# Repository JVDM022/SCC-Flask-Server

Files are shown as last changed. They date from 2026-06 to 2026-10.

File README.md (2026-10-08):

# scc-control-platform

A small SCADA-like research control platform for a thermal SCC/corrosion test rig. Arduino SCC firmware owns rig control behavior, while an Intel NUC USB gateway handles communications to the Flask backend. PostgreSQL stores the time series, and the backend derives alarms, pump-cycle statistics, ML temperature predictions, and advisory MPC heater PWM recommendations. The React HMI dashboard provides live monitoring, trends, alarms, events, ML predictions, MPC output, firmware updates, and equipment health views.

## Architecture

```text
Arduino SCC controller -> USB serial -> Intel NUC gateway -> Flask API -> PostgreSQL
                                                                  |-> alarms and events
                                                                  |-> pump-cycle extraction
                                                                  |-> ML prediction
                                                                  |-> advisory MPC
                                                                  |-> React HMI dashboard
```

## Docker Setup

```bash
docker compose up --build
```

Backend: `http://localhost:5050`  
Frontend: `http://localhost:5173`

## Frontend HMI

The HMI is a React + Vite + TypeScript app in `frontend/hmi-dashboard`. It uses React Query for API polling, Plotly for dark engineering charts, and modular dashboard pages for operations, analytics, ML models, MPC, digital twin simulation, equipment health, event intelligence, and settings.

```bash
cd frontend/hmi-dashboard
npm install
npm run dev
```

## Live Telemetry

The default live path reads Arduino CSV telemetry over USB on the Intel NUC and posts parsed JSON to Flask:

```bash
cd backend
python -m app.services.nuc_gateway --serial-port /dev/ttyACM0 --api-base-url http://localhost:5000
```

Set `API_WRITE_KEY` in both the backend and gateway environment when write authentication is enabled. Common NUC gateway variables:

```text
NUC_SERIAL_PORT=/dev/ttyACM0
NUC_SERIAL_BAUD=115200
SCC_API_BASE_URL=http://localhost:5000
NUC_DEVICE_ID=intel-nuc-gateway
NUC_AVRDUDE_COMMAND=avrdude
NUC_ARDUINO_UPLOAD_BAUD=115200
```

Legacy ESP32 relay telemetry is still supported through MQTT. Devices publish JSON to:

```text
scc/site/<site_id>/rig/<rig_id>/device/<device_id>/telemetry
```

The Flask backend subscribes to Mosquitto when `MQTT_ENABLED=1`, parses MQTT payloads, stores telemetry, and derives alarms, pump-cycle records, ML predictions, and MPC recommendations.

## API Endpoints

- `GET /api/latest`: latest telemetry row.
- `GET /api/history?minutes=60`: telemetry history for plotting.
- `GET /api/events?limit=100`: pump and hard-kill events.
- `GET /api/alarms/active`: active alarms.
- `GET /api/pump-cycles`: extracted pump cycle statistics.
- `GET /api/ml/prediction`: predicted temperatures for +1s, +5s, and +10s when models exist.
- `GET /api/mpc/recommendation`: advisory heater PWM recommendation.
- `POST /api/control/setpoint`: store a desired setpoint command.
- `POST /api/control/power`: queue a controller on/off command through the Intel NUC gateway.
- `POST /api/telemetry`: JSON telemetry ingest used by the Intel NUC gateway and development tools.
- `POST /api/telemetry/csv`: development/manual CSV import, not the live ESP32 path.

## Telemetry Format

Live MQTT telemetry is JSON. The development CSV import endpoint accepts CSV with or without a header. Headerless rows are parsed using this exact order:

```text
event,ms,temp_c,adc,dtemp_c_per_s,setpoint_c,mode,heater_pwm,heating,heater_lockout,pump_enabled,pump_allowed,pump_on,motor_pwm,motor_on_ms,motor_period_ms,temp_before_pump_c,min_temp_after_pump_c,last_pump_drop_c,recovery_time_s,manual_kill,hard_kill,uptime_s
```

Example:

```text
0,123456,126.42,222,-0.1300,125.00,3,184,1,0,1,1,0,155,150,30000,127.20,124.80,2.40,18.50,0,0,300
```

Event codes: `0` normal sample, `1` pump start, `2` pump end, `3` pump recovered, `4` hard kill, `5` sensor fault.

## Safety Philosophy

Arduino firmware and hardware own hard safety. Flask, ML, MPC, and the Intel NUC gateway are monitoring, communications, and advisory layers, not the only protection layer. Heater lockout, manual kill, and hard kill override all recommendations; MPC returns PWM 0 when any of those states is active.

## Manual Emergency Control

The Arduino starts in a fail-safe OFF state. The Operations HMI queues `SET_ON 1` to enable both heater control and the pump timer, and `SET_ON 0` to turn both outputs off. `KILL 1` immediately latches the system OFF; after `KILL 0`, the operator must deliberately select Turn On again. Set `API_WRITE_KEY` on the backend and `VITE_API_WRITE_KEY` on the frontend to the same value when command authentication is enabled. The NUC gateway polls:

```text
/api/firmware/commands/next?device=nuc
```

Pending manual kill and setpoint commands are delivered through that endpoint before Arduino OTA commands. Existing ESP32 relay firmware can still poll with `device=esp32` for legacy deployments.

## Dependency Explanation

- Flask: API server
- SQLAlchemy: ORM
- PostgreSQL: database
- pandas/numpy: data processing
- scikit-learn: ML models
- joblib: model persistence
- matplotlib/plotly: visualization
- APScheduler: background jobs
- pytest: testing
- xgboost/lightgbm: advanced ML models

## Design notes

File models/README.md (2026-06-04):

# Model Artifacts

Optional model files:

- `best_model_1s.joblib`
- `best_model_5s.joblib`
- `best_model_10s.joblib`
- `feature_columns.json`

Each model should predict delta temperature for its horizon. The backend reconstructs future temperature as `current_temp_c + predicted_delta_c`.

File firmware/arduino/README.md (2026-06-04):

# Arduino Firmware

Imported firmware project:

- `SCC-V1.4`: Arduino SCC controller firmware source and tests.

This firmware owns the thermal SCC rig control behavior. The ESP32 project under `firmware/esp32/ESP32-Relay` is only the relay/communications bridge.

The backend expects telemetry in the fixed CSV order documented in `docs/telemetry_format.md`.

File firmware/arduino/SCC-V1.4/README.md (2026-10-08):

# SCC-V1.4 Arduino Firmware

This firmware controls the Arduino Uno side of the SCC controller and emits CSV
telemetry over UART.

## Startup and Power Commands

The controller always boots with the heater and pump off. It will not begin
autotune, heating, or timed pump operation until it receives `SET_ON 1` over
UART. `SET_ON 0` turns both outputs off. `KILL 1` also turns both outputs off
and latches the emergency-stop state; after `KILL 0`, a new `SET_ON 1` command
is required to restart the rig.

## ESP32-Driven Firmware Update Prep

The optional `ENABLE_SOFTWARE_BOOTLOADER_ENTRY` feature adds a small UART command
entry point for an ESP32 to request a safe reset handoff before programming the
Arduino.

This does not flash the Arduino from the Arduino firmware. The ESP32 must act as
the programmer and provide the upload protocol.

When enabled, the Arduino accepts either command line:

```text
ENTER_BOOTLOADER
OTA_PREPARE
```

On a recognized command, the firmware:

- sets heater PWM to `0`
- turns the motor/pump off
- disables normal control outputs
- prints `OTA_READY`
- flushes serial output
- triggers an ATmega328P watchdog reset

The feature is disabled by default so normal builds keep UART output as CSV
telemetry only. Enable it explicitly at compile time, for example:

```ini
build_flags =
  -DENABLE_SOFTWARE_BOOTLOADER_ENTRY=1
```

For a reliable production update path, wire an ESP32 GPIO to the Arduino RESET
line and use that GPIO for bootloader entry/reset timing. Software reset into the
bootloader is bootloader-dependent and can be less reliable than a hardware
reset pulse.

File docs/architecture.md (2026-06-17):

# Architecture

The platform is a small SCADA-like research stack for a thermal SCC/corrosion test rig.

```text
Arduino SCC controller firmware
  -> USB serial
  -> Intel NUC gateway
  -> Flask telemetry and command APIs
  -> PostgreSQL storage
  -> alarm rules, pump-cycle extraction, ML prediction, MPC advisory logic
  -> React HMI dashboard
```

The Arduino firmware owns rig control behavior. The Intel NUC gateway is used only as a communications bridge to move telemetry, commands, and Arduino firmware update requests between the hardware-side controller and backend services. The ESP32 MQTT relay path remains available for legacy deployments.

The backend stores raw telemetry first, then derives alarms, events, pump-cycle records, ML predictions, and MPC recommendations. Live device telemetry enters through the JSON telemetry API when using the NUC gateway, or through MQTT when using the legacy ESP32 relay. The HMI reads backend endpoints through polling so it remains simple to run during early research.

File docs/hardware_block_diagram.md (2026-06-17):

# Hardware Block Diagram

This diagram reflects the current SCC control-platform firmware layout:

- Arduino Uno owns the thermal control loop, sensor readout, heater PWM, and pump/motor PWM.
- Intel NUC acts as the communications bridge between Arduino USB serial and the backend API.
- Arduino firmware updates are flashed from the NUC over USB with `avrdude`.

```mermaid
%%{init: {"theme": "base", "themeVariables": {"background": "#0b0f14", "mainBkg": "#121821", "secondBkg": "#0f151d", "primaryColor": "#121821", "primaryTextColor": "#e5e7eb", "primaryBorderColor": "#1f2937", "lineColor": "#64748b", "secondaryColor": "#0f151d", "tertiaryColor": "#101923", "fontFamily": "Inter, IBM Plex Sans, ui-sans-serif, system-ui, sans-serif", "edgeLabelBackground": "#0b0f14", "clusterBkg": "#0f151d", "clusterBorder": "#1f2937", "titleColor": "#e5e7eb", "nodeTextColor": "#e5e7eb"}}}%%
flowchart LR
  subgraph Rig["Thermal SCC / Corrosion Test Rig"]
    Bath["MgCl2 bath / specimen cell"]
    TempSensor["Temperature sensor / thermistor interface"]
    Heater["Heater element"]
    Pump["Pump / dosing motor"]
  end

  subgraph Power["Power Domains"]
    Logic5V["5 V logic supply"]
    NucPower["Intel NUC power"]
    LoadSupply["Load supply for heater and pump"]
  end

  subgraph Arduino["Arduino Uno SCC Controller"]
    A0["A0 THERM_PIN\nADC temperature input"]
    D6["D6 HEATER_PWM_PIN\nPWM heater command"]
    D9["D9 MOTOR_PIN\nPWM pump/motor command"]
    Serial0["UART Serial @ 115200\nCSV telemetry + commands"]
    Control["Autotune / PID / safety logic\n120-130 C safe window\nheater hard kill at 130 C"]
  end

  subgraph DriverStage["Power Driver Stage"]
    HeaterMosfet["Heater MOSFET / driver"]
    MotorDriver["Motor driver / MOSFET"]
  end

  subgraph NUC["Intel NUC USB Gateway"]
    UsbSerial["USB serial\n115200 baud"]
    Parser["CSV parser\nJSON telemetry poster"]
    CommandPoller["HTTP command poller\nKILL / SETPOINT / ARDUINO_OTA"]
    Avrdude["avrdude Arduino flasher"]
  end

  subgraph LocalStack["Local Computer / Backend Stack"]
    Flask["Flask backend\ntelemetry + command API"]
    Postgres["PostgreSQL"]
    HMI["React HMI dashboard"]
  end

  Bath --> TempSensor
  TempSensor -->|"analog temperature signal"| A0
  A0 --> Control
  Control --> D6
  Control --> D9
  D6 -->|"PWM, max 200/255"| HeaterMosfet
  D9 -->|"PWM: startup 180, run 155"| MotorDriver
  HeaterMosfet -->|"switched load power"| Heater
  MotorDriver -->|"switched load power"| Pump
  Heater --> Bath
  Pump --> Bath

  Serial0 <-->|"CSV telemetry upstream\ncommand lines downstream"| UsbSerial

  UsbSerial --> Parser
  UsbSerial --> Avrdude
  Parser -->|"POST /api/telemetry"| Flask
  CommandPoller <-->|"HTTP polling / command JSON"| Flask
  Avrdude <-->|"download artifact + ack status"| Flask
  Flask --> Postgres
  HMI <-->|"HTTP polling"| Flask

  Logic5V --> Arduino
  NucPower --> NUC
  LoadSupply --> HeaterMosfet
  LoadSupply --> MotorDriver

  classDef field fill:#0f151d,stroke:#22c55e,color:#e5e7eb,stroke-width:1px;
  classDef controller fill:#121821,stroke:#38bdf8,color:#e5e7eb,stroke-width:1px;
  classDef safety fill:#121821,stroke:#ef4444,color:#e5e7eb,stroke-width:1px;
  classDef comm fill:#101923,stroke:#38bdf8,color:#e5e7eb,stroke-width:1px;
  classDef backend fill:#121821,stroke:#64748b,color:#e5e7eb,stroke-width:1px;
  classDef driver fill:#0f151d,stroke:#f59e0b,color:#e5e7eb,stroke-width:1px;
  classDef power fill:#0f151d,stroke:#f59e0b,color:#e5e7eb,stroke-width:1px;

  class Bath,TempSensor,Heater,Pump field;
  class A0,D6,D9,Serial0 controller;
  class Control safety;
  class HeaterMosfet,MotorDriver driver;
  class UsbSerial,Parser,CommandPoller,Avrdude comm;
  class Flask,Postgres,HMI backend;
  class Logic5V,NucPower,LoadSupply power;

  style Rig fill:#0f151d,stroke:#1f2937,color:#e5e7eb
  style Power fill:#0b1118,stroke:#f59e0b,color:#e5e7eb
  style Arduino fill:#0f151d,stroke:#38bdf8,color:#e5e7eb
  style DriverStage fill:#0b1118,stroke:#f59e0b,color:#e5e7eb
  style NUC fill:#0f151d,stroke:#38bdf8,color:#e5e7eb
  style LocalStack fill:#0f151d,stroke:#64748b,color:#e5e7eb
```

## Pin And Signal Summary

| Endpoint | Signal | Notes |
| --- | --- | --- |
| Arduino A0 | Temperature ADC | Uses calibrated linear fit in firmware: `tempC = -0.1871 * adc + 167.97`. |
| Arduino D6 | Heater PWM | Drives heater MOSFET/driver. Firmware clamps heater PWM to `HEATER_PWM_MAX = 200`. |
| Arduino D9 | Pump/motor PWM | Drives pump/motor driver. Startup kick is `180`, normal PWM is `155`. |
| Arduino Serial | UART telemetry/commands | CSV telemetry is emitted at `115200` baud. Optional command handling supports bootloader prep when enabled. |
| Arduino USB | Serial telemetry/commands | Connects directly to the Intel NUC gateway. |
| Intel NUC gateway | USB + HTTP | Parses telemetry, posts to Flask, polls commands, and flashes Arduino `.hex` artifacts with `avrdude`. |

## Backend Interface

Telemetry is posted by the Intel NUC gateway to:

```text
POST /api/telemetry
```

The backend stores raw telemetry first, then derives alarms, pump cycles, ML predictions, and MPC advisory state for the HMI.

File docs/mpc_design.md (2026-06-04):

# MPC Design

The initial MPC module is advisory only. It evaluates a fixed set of candidate heater PWM values:

```python
[0, 64, 128, 184, 220, 255]
```

For each candidate, it estimates the 5-second future temperature using `models/best_model_5s.joblib` when present. If no model is available, the backend uses a simple fallback predictor so the endpoint remains usable during commissioning.

The cost function is:

```text
cost = (predicted_temp - setpoint_c)^2 + 0.0005*pwm^2 + 0.05*(pwm - previous_pwm)^2
```

If hard kill, manual kill, or heater lockout is active, the recommendation is forced to PWM 0.

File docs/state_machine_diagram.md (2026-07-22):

# State Machine Diagram

This diagram reflects the Arduino SCC controller firmware state flow in
`firmware/arduino/SCC-V1.4/src/controller.cpp` and
`firmware/arduino/SCC-V1.4/src/main.cpp`.

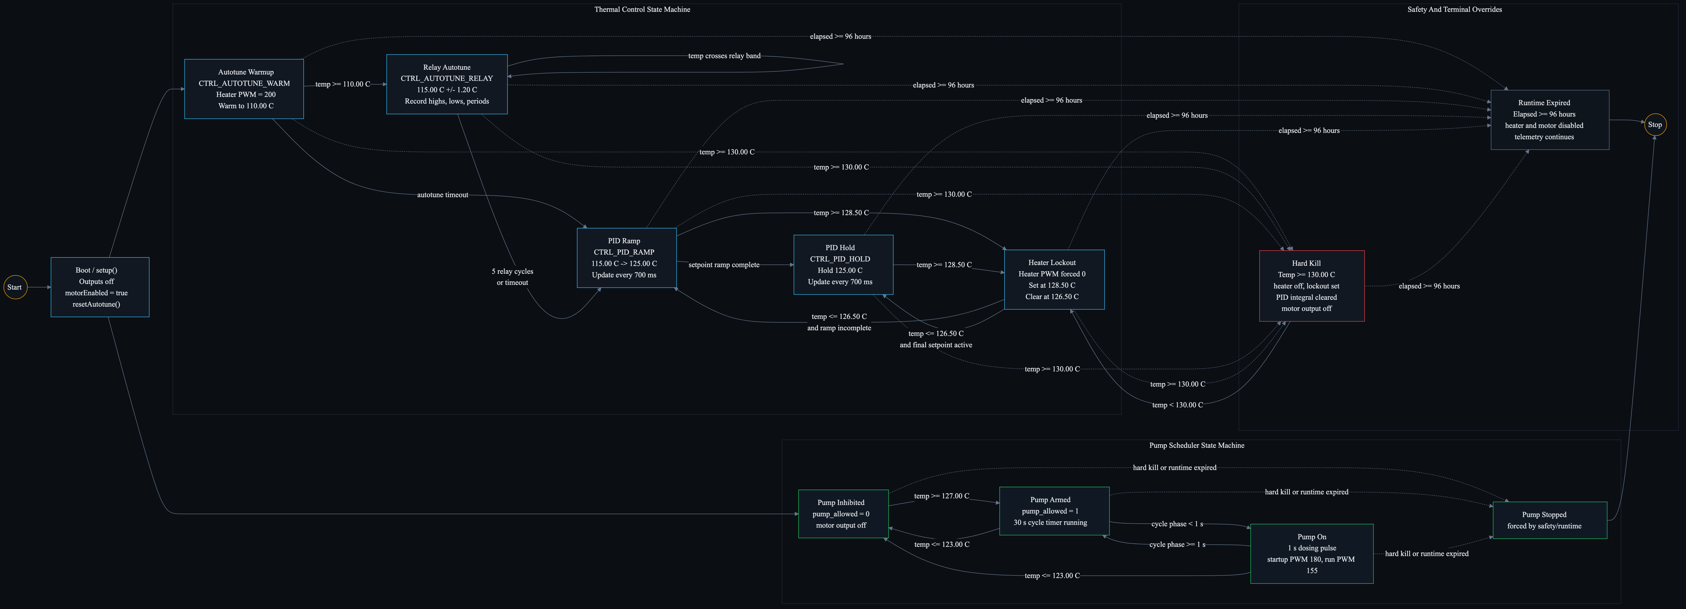
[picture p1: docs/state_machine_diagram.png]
SCC controller state machine


```mermaid
%%{init: {"theme": "base", "themeVariables": {"background": "#0b0f14", "mainBkg": "#121821", "secondBkg": "#0b0f14", "primaryColor": "#121821", "primaryTextColor": "#e5e7eb", "primaryBorderColor": "#1f2937", "lineColor": "#64748b", "secondaryColor": "#0b0f14", "tertiaryColor": "#0b0f14", "fontFamily": "Inter, IBM Plex Sans, ui-sans-serif, system-ui, sans-serif", "edgeLabelBackground": "#0b0f14", "clusterBkg": "#0b0f14", "clusterBorder": "#1f2937", "titleColor": "#e5e7eb", "nodeTextColor": "#e5e7eb"}}}%%
flowchart LR
  Start((Start)) --> Boot["Boot / setup()\nOutputs off\nmotorEnabled = true\nresetAutotune()"]

  subgraph Thermal["Thermal Control State Machine"]
    Warmup["Autotune Warmup\nCTRL_AUTOTUNE_WARMUP\nHeater PWM = 200\nWarm to 110.00 C"]
    Relay["Relay Autotune\nCTRL_AUTOTUNE_RELAY\n115.00 C +/- 1.20 C\nRecord highs, lows, periods"]
    Ramp["PID Ramp\nCTRL_PID_RAMP\n115.00 C -> 125.00 C\nUpdate every 700 ms"]
    Hold["PID Hold\nCTRL_PID_HOLD\nHold 125.00 C\nUpdate every 700 ms"]
    Lockout["Heater Lockout\nHeater PWM forced 0\nSet at 128.50 C\nClear at 126.50 C"]

    Warmup -->|"temp >= 110.00 C"| Relay
    Warmup -->|"autotune timeout"| Ramp
    Relay -->|"5 relay cycles\nor timeout"| Ramp
    Relay -->|"temp crosses relay band"| Relay
    Ramp -->|"setpoint ramp complete"| Hold
    Ramp -->|"temp >= 128.50 C"| Lockout
    Hold -->|"temp >= 128.50 C"| Lockout
    Lockout -->|"temp <= 126.50 C\nand ramp incomplete"| Ramp
    Lockout -->|"temp <= 126.50 C\nand final setpoint active"| Hold
  end

  Boot --> Warmup

  subgraph Pump["Pump Scheduler State Machine"]
    PumpInhibited["Pump Inhibited\npump_allowed = 0\nmotor output off"]
    PumpArmed["Pump Armed\npump_allowed = 1\n30 s cycle timer running"]
    PumpOn["Pump On\n1 s dosing pulse\nstartup PWM 180, run PWM 155"]
    PumpStopped["Pump Stopped\nforced by safety/runtime"]

    PumpInhibited -->|"temp >= 125.00 C"| PumpArmed
    PumpArmed -->|"cycle phase < 1 s"| PumpOn
    PumpOn -->|"cycle phase >= 1 s"| PumpArmed
    PumpArmed -->|"temp <= 123.00 C"| PumpInhibited
    PumpOn -->|"temp <= 123.00 C"| PumpInhibited
  end

  Boot --> PumpInhibited

  subgraph Overrides["Safety And Terminal Overrides"]
    HardKill["Hard Kill\nTemp >= 130.00 C\nheater off, lockout set\nPID integral cleared\nmotor output off"]
    RuntimeExpired["Runtime Expired\nElapsed >= 96 hours\nheater and motor disabled\ntelemetry continues"]
    Stop((Stop))
  end

  Warmup -.->|"temp >= 130.00 C"| HardKill
  Relay -.->|"temp >= 130.00 C"| HardKill
  Ramp -.->|"temp >= 130.00 C"| HardKill
  Hold -.->|"temp >= 130.00 C"| HardKill
  Lockout -.->|"temp >= 130.00 C"| HardKill
  HardKill -->|"temp < 130.00 C"| Lockout

  Warmup -.->|"elapsed >= 96 hours"| RuntimeExpired
  Relay -.->|"elapsed >= 96 hours"| RuntimeExpired
  Ramp -.->|"elapsed >= 96 hours"| RuntimeExpired
  Hold -.->|"elapsed >= 96 hours"| RuntimeExpired
  Lockout -.->|"elapsed >= 96 hours"| RuntimeExpired
  HardKill -.->|"elapsed >= 96 hours"| RuntimeExpired
  PumpInhibited -.->|"hard kill or runtime expired"| PumpStopped
  PumpArmed -.->|"hard kill or runtime expired"| PumpStopped
  PumpOn -.->|"hard kill or runtime expired"| PumpStopped
  RuntimeExpired --> Stop
  PumpStopped --> Stop

  classDef normal fill:#121821,stroke:#38bdf8,color:#e5e7eb,stroke-width:1px;
  classDef pump fill:#101923,stroke:#22c55e,color:#e5e7eb,stroke-width:1px;
  classDef safety fill:#121821,stroke:#ef4444,color:#e5e7eb,stroke-width:1px;
  classDef terminal fill:#0f151d,stroke:#64748b,color:#e5e7eb,stroke-width:1px;
  classDef start fill:#0f151d,stroke:#f59e0b,color:#e5e7eb,stroke-width:1px;

  class Boot,Warmup,Relay,Ramp,Hold,Lockout normal;
  class PumpInhibited,PumpArmed,PumpOn,PumpStopped pump;
  class HardKill safety;
  class RuntimeExpired terminal;
  class Start,Stop start;

  style Thermal fill:#0b0f14,stroke:#1f2937,color:#e5e7eb
  style Pump fill:#0b0f14,stroke:#1f2937,color:#e5e7eb
  style Overrides fill:#0b0f14,stroke:#1f2937,color:#e5e7eb
```

## State Notes

| State | Meaning |
| --- | --- |
| `AutotuneWarmup` | Initial control mode. Heater runs at fixed autotune PWM until the bath reaches `110.00 C`. |
| `AutotuneRelay` | Relay autotune oscillates around `115.00 C +/- 1.20 C` and records up to five cycles. |
| `PidRamp` | PID starts at the autotune target and ramps the active setpoint toward `125.00 C`. |
| `PidHold` | PID holds the final `125.00 C` setpoint. |
| `HeaterLockout` | Heater output is held off after `128.50 C` until temperature falls to `126.50 C`. |
| `HardKill` | At `130.00 C`, heater and motor outputs are forced off and lockout is set. |
| `RuntimeExpired` | After `96 hours`, heater and motor are disabled and the loop only emits telemetry. |
| `PumpScheduler` | Independent pump timer that enables dosing only with thermal headroom. |

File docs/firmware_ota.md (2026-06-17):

# Firmware Artifact Upload and OTA Commands

The HMI firmware page can upload firmware artifacts to the backend and queue OTA
commands. Arduino `.hex` updates are now handled by the Intel NUC USB gateway.
The legacy ESP32 relay command path remains available for older deployments.

## Artifact URLs

Artifacts are stored under `FIRMWARE_STORAGE_DIR`, which defaults to
`backend/storage/firmware`. They are served from:

```text
GET /firmware/artifacts/<filename>
```

Set `PUBLIC_BASE_URL` to the backend origin reachable by the NUC so queued OTA
commands contain artifact URLs the gateway can download.

## Command Lifecycle

The dashboard queues commands with:

```text
POST /api/firmware/commands
```

The Intel NUC gateway polls:

```text
GET /api/firmware/commands/next?device=nuc
```

The backend marks a command as `sent` when it is fetched. This avoids repeated
polling re-running the same OTA command. The NUC gateway acknowledges with:

```text
POST /api/firmware/commands/<cmd_id>/ack
```

Valid acknowledgement states are `started`, `success`, and `failed`.

## Intel NUC Arduino Flashing

Run the gateway on the NUC that is connected to the Arduino USB port:

```bash
cd backend
python -m app.services.nuc_gateway --serial-port /dev/ttyACM0 --api-base-url http://localhost:5000
```

Arduino flashing uses `avrdude` by default:

```text
avrdude -v -p atmega328p -c arduino -P <serial-port> -b 115200 -D -U flash:w:<artifact.hex>:i
```

Override the command and board parameters with `NUC_AVRDUDE_COMMAND`,
`NUC_ARDUINO_MCU`, `NUC_ARDUINO_PROGRAMMER`, and
`NUC_ARDUINO_UPLOAD_BAUD` if the NUC has a different Arduino toolchain.

## Safety Notes

- Do not expose firmware upload endpoints publicly without authentication.
- Firmware upload should require login and role permissions before production use.
- HTTPS is strongly recommended for OTA artifact URLs.
- Arduino `.hex` upload queues an `ARDUINO_OTA` command. The NUC gateway
  downloads that artifact, closes the serial monitor, runs `avrdude`, reopens
  serial, records OTA status, and acknowledges success or failure.
- ESP32 `.bin` upload remains available for legacy relay firmware only.

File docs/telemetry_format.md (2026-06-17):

# Telemetry Format

The Arduino emits CSV telemetry over USB. The Intel NUC gateway parses each row and posts JSON to the backend. CSV import tools may provide either a header plus row or a row without a header. If the header is missing, the backend parses values using this fixed column order:

```text
event,ms,temp_c,adc,dtemp_c_per_s,setpoint_c,mode,heater_pwm,heating,heater_lockout,pump_enabled,pump_allowed,pump_on,motor_pwm,motor_on_ms,motor_period_ms,temp_before_pump_c,min_temp_after_pump_c,last_pump_drop_c,recovery_time_s,manual_kill,hard_kill,uptime_s
```

Example row:

```text
0,123456,126.42,222,-0.1300,125.00,3,184,1,0,1,1,0,155,150,30000,127.20,124.80,2.40,18.50,0,0,300
```

Event codes:

- `0`: normal sample
- `1`: pump start
- `2`: pump end
- `3`: pump recovered
- `4`: hard kill
- `5`: sensor fault

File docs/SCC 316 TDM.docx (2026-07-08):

Stainless Steel 316 Stress Corrosion Cracking System

Technical Design, Operations, and Maintaince Manual

Document Number: SCC-TDM-001

Revision: 0.1 Draft

Author: John Jin

Date: June 9, 2026

Revision History:

Revision | Date | Author | Description
0.1 | June 9, 2026 | John Jin | Initial Draft

# 1. Introduction

## 1.1. Purpose

The Stress Corrosion Cracking (SCC) test system is an automated control system designed to heat the specimen and pump corrosive medium, such as magnesium chloride (MgCl2), while the sample undergoes creep loading. The platform integrates embedded hardware, process control algorithms, wireless communication, database infrastructure, and data analysis into a unified architecture [1–10].

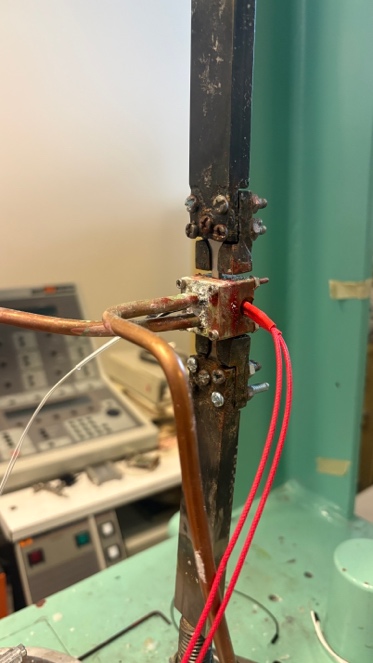
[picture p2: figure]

Fig 1. Testing setup

## 1.2. Scope

This document will include the following facets of the system:

- System architecture
- Hardware design
- Firmware design
- Backend infrastructure
- Database structure
- Control algorithms
- Safety systems
- Testing procedures
- Operational procedures

## 1.3. Objectives

The primary objectives of the SCC platform are:

1. Reliable process

The system must be designed to repeat the experiment process repeatedly. This process should be capable of being repeated with minimal human intervention to address any potential issues that may arise.

2. Reliable monitoring method

The system must be monitored with ease and reliability. All sensors must remain operational for an extended period beyond the duration of a single testing experiment.

3. Automated test control (temperature, pump frequency, etc.)

The PID system should be equipped with self-tuning capabilities and housed in a secure environment.

4. Safe heater operation

The temperature should not exceed 20 degrees Celsius above the set point or 350 degrees Celsius.

5. Continuous data logging

It’s important to log crucial parameters, including temperature, pump cycle, and time, in CSV format. These parameters encompass any data required for stress corrosion testing analysis, physics-informed machine learning models, or digital twins.

6. Remote monitoring capability

The parameters of the heater and pump should be adjustable remotely via the cloud. Firmware for both ESP32 and Arduino Uno R3 should support Over the Air (OTA) updates. Additionally, the Kill Command should also be executed via OTA.

# 2. System Requirements

This system is employed for conducting stress corrosion cracking experiments. It provides heating and a corrosive medium for the dog-bone samples during creep loading. The cartridge heater enables users to set the desired temperature, while the peristaltic pump propels MgCl2 (corrosive medium) through the copper pipes and cells, exposing the samples to the corrosive environment. The entire system should function in a quasi-automated mode.

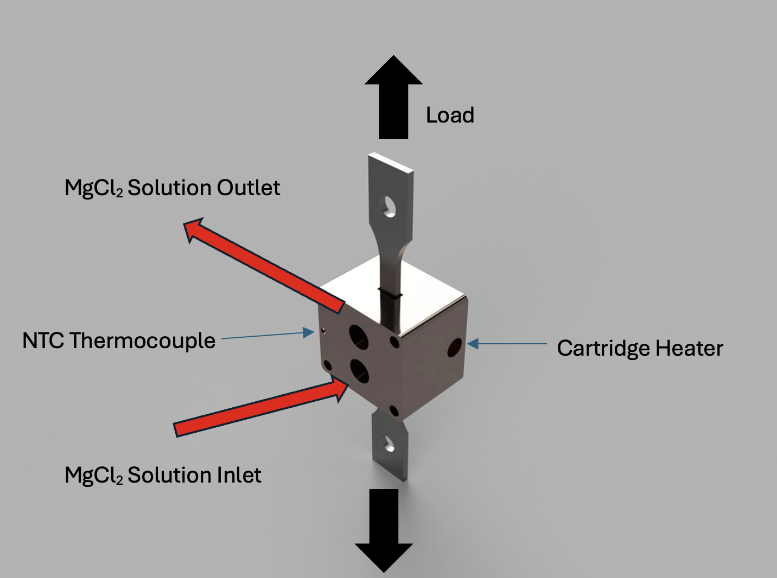
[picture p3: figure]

Fig 2. The hardware schematic of the system

## 2.1. Functional Requirements

ID | Requirement
FR-001 | Measure system temperature
FR-002 | Control heater output
FR-003 | Control pump circulations
FR-004 | Log data
FR-005 | Provide a method to monitor remotely
FR-006 | Execute safety shutdowns

Table 1. List of required functions for the system to perform

## 2.2. Performance Requirements

ID | Requirement | Target
PR-001 | Telemetry update rate | 1Hz
PR-002 | Data retention | ≥ 1 year
PR-003 | Uptime | >99%
PR-004 | Network Latency | <2 s

Table 2. List of performance targets the system needs to achieve

# 3. System Overview

## 3.1. Architecture

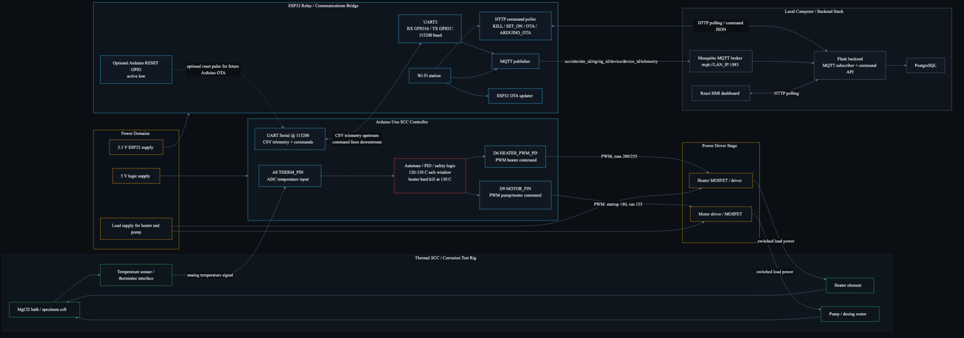
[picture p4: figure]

Fig 3. End-to-end system architecture

Fig 3 illustrates the end-to-end architecture of the SCC testing platform. The NTC thermistor and cartridge heater interface with the Arduino controller, which performs local control and data acquisition functions using the hardware components summarized in Table 3. The Arduino communicates with an ESP32 module that serves as a telemetry and command relay between the field hardware and backend infrastructure.

Sensor measurements, process data, and control messages are transmitted through the MQTT broker to the Flask API, which acts as the central integration layer for data management, command processing, analytics, and operator interaction. The software components that support these functions are summarized in Table 4. Processed data are stored in a PostgreSQL database, enabling long-term data retention, historical analysis, and performance monitoring.

The backend provides additional services, including alarm generation, pump-cycle extraction, machine-learning-based prediction, and advisory Model Predictive Control (MPC). Real-time communication between the backend and operator interface is implemented using a Socket.IO event bus [10]. This continuously updates the Human–Machine Interface (HMI) dashboard with process status, alarms, trends, and operator recommendations.

Operator-issued commands are routed through the Flask API and command store to the ESP32 command bridge, enabling remote actuation and over-the-air (OTA) firmware deployment. By separating field control, data acquisition, analytics, data storage, and user interaction into modular subsystems, the proposed architecture improves system scalability, maintainability, reliability, and future extensibility.

## 3.2. Hardware Components

The SCC testing platform consists of several hardware subsystems responsible for sensing, actuation, control, and communication. The primary hardware components and their functions are summarized in Table 3.

Component | Function
Arduino | Embedded controller
ESP32 | Telemetry and command relay
Thermistor | Temperature measurement
Cartridge heater | Thermal control
Pump | Fluid Circulation
SCC Shield | Power switching

Table 3. List of hardware in the system

  3.3. Software Components

The software architecture is organized into modular services responsible for control, communication, data management, and user interaction using MQTT, Flask, PostgreSQL, Socket.IO, and Docker technologies [1,4–10]. The major software components used in the SCC platform are summarized in Table 4.

Components | Function
Arduino Firmware | Local Control
ESP32 Firmware | Relay telemetry and commands
MQTT Broker | Messaging
Flask API | Backend services
Flask Server | Data Login and HMI interface
PostgreSQL | Data Storage
Dashboard | User interface HMI

Table 4. List of software tools used in the system

# 4. Hardware Design

## 4.1. Hardware Block Diagram

Fig 4 shows the hardware block diagram of the SCC testing platform. The system is centered around an Arduino UNO R3 microcontroller, which executes the local temperature control and pump management logic. The Arduino interfaces with a custom SCC Shield that provides sensor acquisition, power switching, and hardware interfacing functions. An NTC thermistor is connected to the SCC Shield for temperature measurement, while a cartridge heater and peristaltic pump are controlled through the shield to regulate the thermal and fluid circulation conditions of the SCC test environment. An ESP32 module serves as a communication bridge between the embedded controller and the supervisory control system. Through a Wi-Fi connection, the ESP32 exchanges telemetry and control commands with a remote Flask server, enabling real-time monitoring, data logging, and remote operation of the testing platform. This architecture separates local control functions from supervisory communication tasks, improving system modularity, maintainability, and scalability.

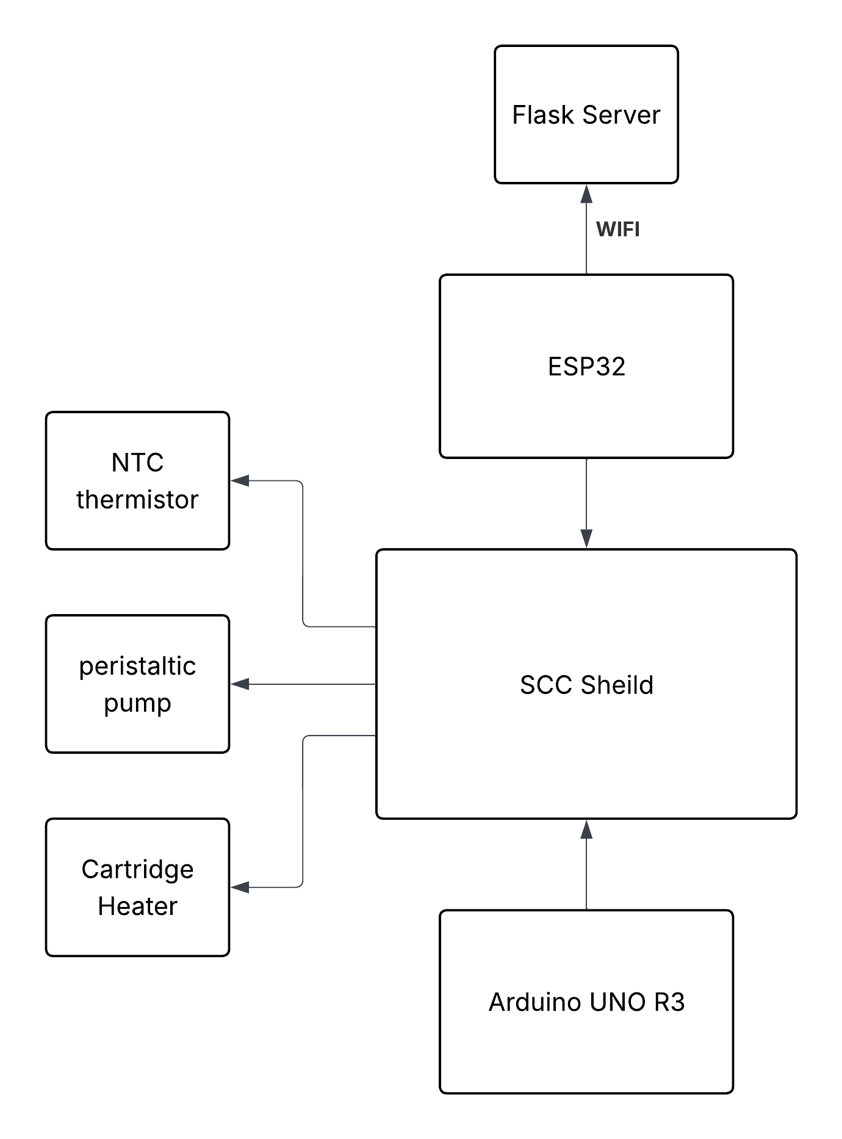
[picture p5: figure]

Fig 4. Hardware Block Diagram of the SCC Testing Platform

- Arduino Uno R3

Purpose: The Arduino Uno R3 serves as the primary embedded controller for the SCC testing platform and is based on the ATmega328P microcontroller architecture [3,15]. It acquires temperature measurements from the NTC thermistor, executes local control logic, manages heater and pump operation, and communicates process data to the ESP32 communication module.

Key Spec:

  - Microcontroller: ATmega328P
  - Operating Voltage: 5 V
  - Clock Speed: 16 MHz
  - Digital I/O Pins: 14
  - Analog Input Channels: 6
  - Communication Interfaces: UART, I²C, SPI

Firmware version: SCC V1.4

- ESP32

Purpose: The ESP32 functions as the communication bridge between the embedded control hardware and the supervisory control system using integrated Wi-Fi communication capabilities [2]. It receives telemetry data from the Arduino, publishes process information through MQTT, receives remote commands, and supports over-the-air (OTA) firmware updates.

Key Spec:

  - Processor: Dual-core Xtensa LX6
  - Clock Speed: Up to 240 MHz
  - Wireless Connectivity: 2.4 GHz Wi-Fi and Bluetooth
  - Flash Memory: 4 MB
  - Communication Interfaces: UART, SPI, I²C

Firmware version: ESP32-Relay

- Intel NUC

Purpose: The Intel NUC serves as the local supervisory computer hosting the Flask backend, MQTT broker, PostgreSQL database, and analytics services [14], MQTT broker, PostgreSQL database, data historian, alarm processing services, machine learning models, and Human–Machine Interface (HMI).

Key Spec:

  - Processor: Intel Core Series Processor
  - Operating System: Ubuntu Linux 24.04 LTS
  - Memory: 8 GB DDR4 RAM
  - Storage: 125 GB SSD
  - Network Connectivity: Gigabit Ethernet and Wi-Fi

Firmware version: SCC Control V0.1.1.4

  4.2. Sensor System
- Temperature Sensor:

Type: Negative Temperature Coefficient (NTC) Thermistor

Purpose:
The NTC thermistor provides continuous temperature measurement of the SCC test environment. The Arduino controller uses the sensor to regulate heater operation, monitor process conditions, and provide temperature feedback for data logging and future advanced control applications.

Sampling Method:
Analog voltage measurement through the Arduino Uno R3 analog-to-digital converter (ADC).

## 4.3. Shield Circuit

Overview of system shield design:

The SCC Shield is a custom-designed interface and power-control board that serves as the hardware integration layer between the Arduino Uno R3 and the SCC test rig components. The shield provides sensor signal conditioning, power distribution, and actuator control functions required for automated operation of the corrosion testing platform. Temperature measurements from the NTC thermistor are routed through an analog conditioning circuit and supplied to the Arduino’s analog-to-digital converter (ADC) for real-time temperature monitoring. High-current switching circuitry on the shield enables the Arduino to safely control the cartridge heater and peristaltic pump using low-voltage digital control signals. The shield also provides electrical isolation between low-power control electronics and higher-power load circuits, improving system reliability and protecting the microcontroller from electrical transients generated by inductive loads.

In addition to power-switching functionality, the SCC Shield consolidates wiring connections into a single interface board, simplifying system assembly, maintenance, and troubleshooting. The modular design allows sensors, actuators, and communication hardware to be connected through standardized connectors while maintaining compatibility with the Arduino platform. This architecture reduces wiring complexity and provides a scalable foundation for future expansion of sensing, control, and data acquisition capabilities.

Schematic:

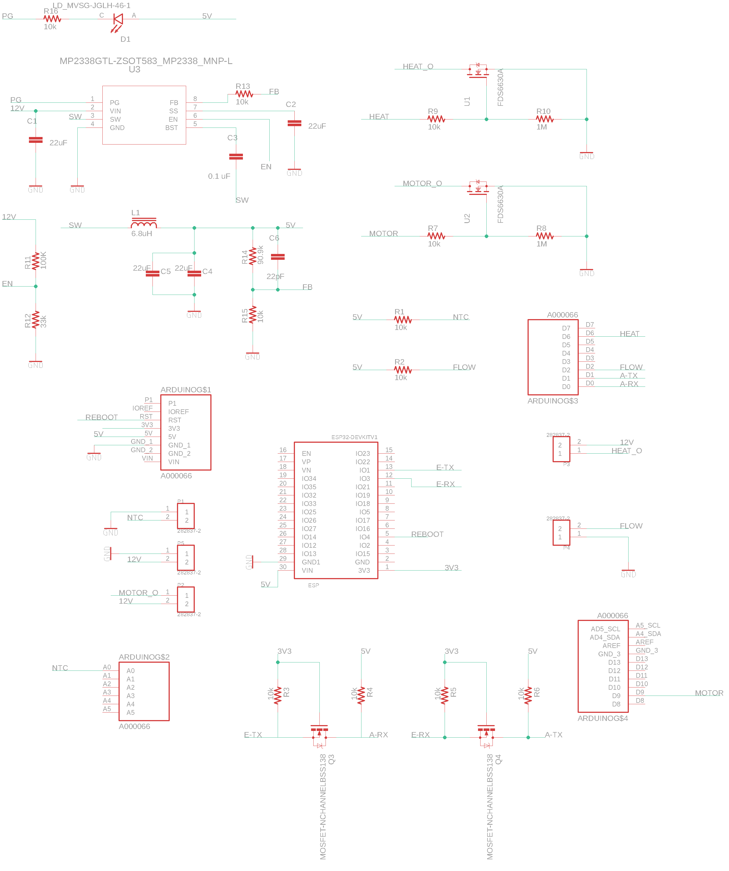
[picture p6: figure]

Fig 5. SCC Shield Electrical Schematic

Board Layout:

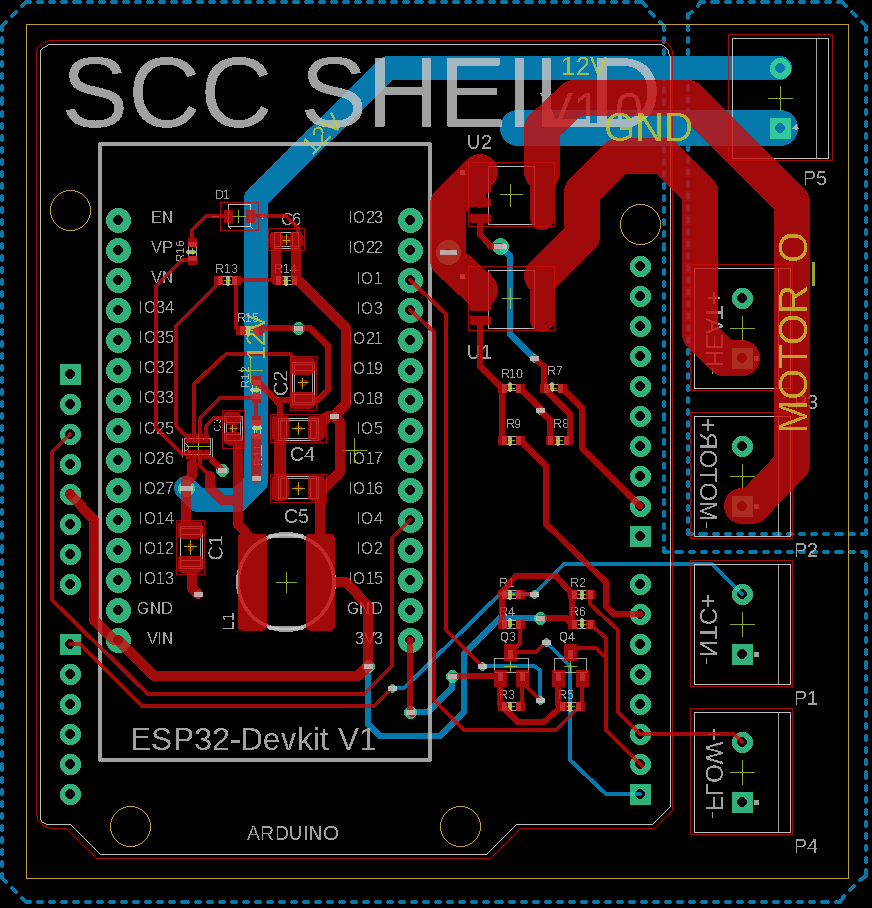
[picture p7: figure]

Fig 6. SCC shield board layout

- Heater Control Circuit

Description:

The heater control circuit provides low-side switching of the cartridge heater using an N-channel MOSFET (U1, FDS6630A). A digital output from the Arduino drives the MOSFET gate through a 10 kΩ gate resistor (R9), allowing the microcontroller to enable or disable heater power. A 1 MΩ pull-down resistor (R10) ensures that the MOSFET remains off during startup, reset conditions, or when the control signal is disconnected. The heater is supplied from the 12 V power rail and is switched under software control to maintain the desired SCC test temperature. This configuration provides efficient switching with minimal power dissipation while electrically isolating the microcontroller from the heater load current.

Operating Voltage: 12 VDC

Maximum Current: Determined by MOSFET rating and power connector limitations

Switching Method: Digital low-side MOSFET switching

Protection Features:

  - Gate pull-down resistor to prevent unintended activation
  - Logic-level MOSFET operation
  - Separation of control and power paths
  - Pump Control Circuit
- Pump Control Circuit

Description:

The pump control circuit uses a second N-channel MOSFET (U2, FDS6630A) to control power delivery to the peristaltic circulation pump. The Arduino drives the MOSFET gate through resistor R7, while pull-down resistor R8 maintains the MOSFET in an off state when no control signal is present. The pump receives power from the 12 V supply and is activated periodically according to the SCC control algorithm to circulate solution through the test apparatus. The MOSFET-based design enables reliable switching while minimizing mechanical wear associated with relay-based control methods.

CAUTION: Use a minimum 14 AWG wire for all motor power connections. The peristaltic pump can draw significant startup and operating current, and undersized wiring may result in excessive voltage drop, overheating, reduced motor performance, or potential damage to wiring and connectors.

Operating Voltage: 12 VDC

Current Draw: Dependent on pump operating conditions

Switching Method: Digital low-side MOSFET switching

Protection Features:

  - Gate pull-down resistor to prevent unintended activation
  - Logic-level MOSFET operation
  - Dedicated power routing for actuator loads

# 5. Software Design

## 5.1. Firmware Architecture

Fig 7 presents the operating state machine implemented within the SCC testing platform firmware. The control logic is organized into six primary operating states: Startup, Idle, Heating, Pumping, Lockout, and Emergency Shutdown. Measured temperature, user-defined setpoints, pump scheduling requirements, and safety conditions determine state transitions. During normal operation, the controller transitions from Startup to Idle, where system readiness is verified. When the measured temperature falls below the configured setpoint, the controller enters the Heating state and activates the cartridge heater. Once the target temperature is reached, the system returns to Idle and periodically executes Pumping cycles to circulate the test solution. Safety monitoring is continuously active throughout all operating states. If an abnormal temperature drop is detected following a pump cycle, the controller enters Lockout mode to prevent ineffective heating and excessive actuator cycling. Critical faults, including excessive temperature, sensor failure, or manual emergency stop commands, force the system into Emergency Shutdown mode, where all outputs are disabled until operator intervention occurs. This state-based architecture improves system reliability, predictability, and operational safety by clearly separating normal control functions from fault-handling behavior.

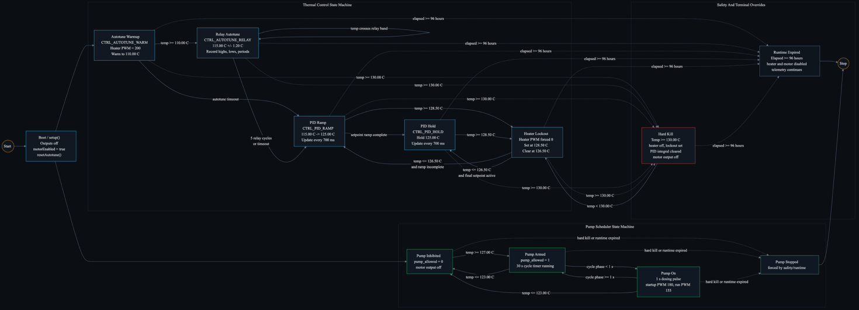
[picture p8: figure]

Fig7. SCC Control State Machine Annotation

## 5.2. Operating States

  1. Startup

The Startup state is entered immediately after power-up or system reset. During this phase, the controller initializes hardware peripherals, verifies sensor communication, loads configuration parameters, and establishes communication with the ESP32 telemetry module. All outputs remain disabled until initialization is successfully completed. Upon successful startup, the controller transitions to the Idle state.

  2. Idle

The Idle state represents the normal standby operating condition. In this state, the controller continuously monitors process temperature, evaluates pump scheduling timers, and checks safety conditions while maintaining all actuators in a safe state. If the measured temperature falls below the desired setpoint, the system transitions to the Heating state. If a scheduled circulation cycle is required and operating conditions permit, the controller transitions to the Pumping state.

  3. Heating

The Heating state regulates the cartridge heater to raise the process temperature toward the user-defined setpoint. Temperature measurements from the NTC thermistor are continuously monitored to prevent overheating and ensure stable thermal control. When the target temperature is achieved, the heater is disabled and the controller returns to the Idle state. Safety monitoring remains active throughout the heating process.

  4. Pumping

The Pumping state activates the circulation pump for a predefined duration to ensure fluid mixing and representative temperature measurements. During pump operation, the controller records thermal response characteristics, including temperature drop and recovery behavior. Upon completion of the pump cycle, the system returns to the Idle state. If abnormal cooling or unsafe operating conditions are detected, the controller may transition to the Lockout or Emergency Shutdown state.

  5. Lockout

The Lockout state is a protective operating mode used to prevent repeated heating and pumping cycles under unfavorable conditions. Lockout may be triggered when the temperature fails to recover adequately after a pump cycle or when operating limits defined by the control strategy are exceeded. While in Lockout, heater and pump operations are restricted until acceptable process conditions are restored. Once recovery criteria are met, the controller automatically returns to the Idle state.

  6. Emergency Shutdown

The Emergency Shutdown state is the highest-priority safety state. It is entered whenever a critical fault condition is detected, such as excessive temperature, sensor failure, communication failure, hardware fault, or a manual emergency stop command. Upon entry, all actuators are immediately disabled and an emergency event is logged and transmitted to the backend system. Recovery from Emergency Shutdown requires operator acknowledgement and corrective action before normal operation can resume.

## 5.3. Event Codes

The SCC firmware records key operational events using a standardized event-code system to support data logging, diagnostics, and backend analytics. Each event is transmitted through the telemetry interface and stored within the database, allowing system behavior to be reconstructed during testing and fault investigation. The event codes used by the platform are summarized in table 5.

Code | Event
0 | Normal Sample
1 | Pump start
2 | Pump end
3 | Recovery complete
4 | Hard kill

Table 5. Event codes generated by the SCC firmware for operational logging and system monitoring.

## 5.4. MQTT Topics

MQTT serves as the primary messaging layer between the ESP32 gateway and the backend infrastructure and enables lightweight publish-subscribe communication for industrial telemetry applications [1,7]. Topic namespaces are structured using site, rig, and device identifiers to support multi-device deployments and simplify message routing. Telemetry topics provide real-time process data, while dedicated status, alarm, heartbeat, and OTA topics support operational monitoring, fault management, and firmware lifecycle control. The MQTT topic definitions used by the SCC platform are listed in Table 6.

Topic | Direction | Description
scc/site/<site_id>/rig/<rig_id>/device/<device_id>/telemetry | Publish | Live ESP32 telemetry
scc/site/<site_id>/rig/<rig_id>/device/<device_id>/ | Publish | Device state
scc/site/<site_id>/rig/<rig_id>/device/<device_id>/alarm | Publish | Device alarms
scc/site/<site_id>/rig/<rig_id>/device/<device_id>/heartbeat | Publish | Device heartbeat
scc/site/<site_id>/rig/<rig_id>/device/<device_id>/ota/status | Publish | OTA status

Table 6. MQTT topics used for device telemetry, status reporting, alarm notification, heartbeat monitoring, and OTA firmware management within the SCC platform.

# 6. Database Design

## 6.1. Database Overview

The SCC platform utilizes a PostgreSQL database as the central repository for process telemetry, alarms, events, and predictive analytics data [4]. MQTT message logs, system events, alarms, pump-cycle statistics, machine-learning (ML) prediction outputs, model predictive control (MPC) recommendations, and firmware update records. Telemetry data are generated by the Arduino controller, transmitted through the ESP32 communication gateway using MQTT, processed by the Flask backend, and stored within the database for visualization, analytics, alarm generation, and decision-support functions.

The database architecture provides persistent storage for both real-time and historical process information, enabling trend analysis, fault investigation, predictive modeling, and long-term system performance evaluation.

Database Engine: PostgreSQL

Backend ORM: SQLAlchemy [9]

Primary Data Source: ESP32 MQTT Telemetry

Primary Data Table: telemetry

Fig 8 illustrates the database architecture and data flow implemented within the SCC platform.

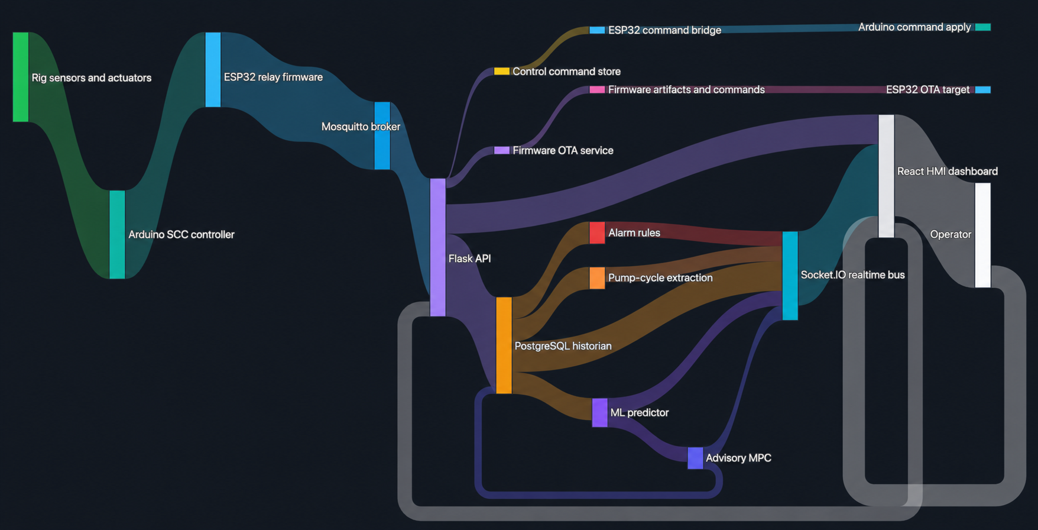
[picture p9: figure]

Fig 8. SCC database flow chart

## 6.2. Process Data Table

The telemetry table serves as the primary repository for process measurements and controller status information. Each telemetry record represents a complete snapshot of system operation at a specific point in time, including temperature measurements, controller states, pump metrics, safety indicators, and operational events. This structure enables historical reconstruction of system behavior, alarm analysis, machine-learning model training, and development of advisory control strategies.

The telemetry table schema is summarized in Table 7.

Table 7. Telemetry table schema used for storage of process measurements, controller states, safety indicators, and pump-cycle metrics within the SCC platform.

Field | Type | Key | Description
id | SERIAL | Primary Key | Unique telemetry record identifier
created_at | TIMESTAMPTZ | Indexed | Timestamp when the telemetry sample was stored
site_id | VARCHAR(80) | Indexed | Site identifier
rig_id | VARCHAR(120) | Indexed | Test rig identifier
device_id | VARCHAR(120) | Indexed | ESP32 device identifier
mqtt_topic | VARCHAR(255) | | MQTT topic associated with the received message
raw_payload | JSONB | | Original MQTT payload stored for traceability and debugging
event | INTEGER | | Event code generated by the controller
ms | INTEGER | | Controller runtime in milliseconds
temp_c | DOUBLE PRECISION | | Measured process temperature (°C)
adc | INTEGER | | Raw analog-to-digital converter value
dtemp_c_per_s | DOUBLE PRECISION | | Temperature rate of change (°C/s)
setpoint_c | DOUBLE PRECISION | | Temperature setpoint (°C)
mode | INTEGER | | Controller operating mode
heater_pwm | INTEGER | | Heater PWM duty cycle command
heating | INTEGER | | Heater active status flag
heater_lockout | INTEGER | | Heater lockout status flag
pump_enabled | INTEGER | | Pump enabled status flag
pump_allowed | INTEGER | | Pump permission status flag
pump_on | INTEGER | | Pump running status flag
motor_pwm | INTEGER | | Pump motor PWM duty cycle
motor_on_ms | INTEGER | | Pump activation duration (ms)
motor_period_ms | INTEGER | | Pump cycle period (ms)
temp_before_pump_c | DOUBLE PRECISION | | Temperature immediately before pump activation (°C)
min_temp_after_pump_c | DOUBLE PRECISION | | Minimum temperature observed after pump activation (°C)
last_pump_drop_c | DOUBLE PRECISION | | Temperature drop caused by the most recent pump cycle (°C)
recovery_time_s | DOUBLE PRECISION | | Temperature recovery time following a pump cycle (s)
manual_kill | INTEGER | | Manual emergency stop status flag
hard_kill | INTEGER | | Hard safety shutdown status flag
uptime_s | INTEGER | | Device uptime in seconds

Table 7. Telemetry table schema used for storage of process measurements, controller states, safety indicators, and pump-cycle metrics within the SCC platform.

The raw_payload field is stored as a PostgreSQL JSONB object to preserve the original MQTT message structure and provide traceability for debugging, validation, and future schema extensions.

## 6.3. Supporting Tables

In addition to the primary telemetry table, several supporting tables are used to manage events, alarms, firmware updates, machine-learning outputs, and control commands. These tables provide separation of concerns while maintaining relationships with the primary telemetry records.

Table 8. Supporting database tables and their functions.

Table | Purpose
events | Stores pump start, pump end, recovery, and hard-kill events
alarms | Stores active and cleared alarm records
pump_cycles | Stores pump-cycle recovery and temperature-drop statistics
devices | Tracks device identity, online status, heartbeat, and MQTT activity
mqtt_message_log | Stores received MQTT messages and validation status
ml_predictions | Stores machine-learning temperature predictions
mpc_recommendations | Stores advisory heater PWM recommendations
control_commands | Stores backend setpoint commands
firmware_devices | Tracks firmware status for connected devices
firmware_update_events | Logs firmware and OTA update events
firmware_artifacts | Stores uploaded firmware artifact metadata
firmware_commands | Stores firmware update commands and acknowledgements

Table 8. Supporting database tables and their functions.

## 6.4. Relationships

Relationships between tables are implemented using foreign-key references to maintain data integrity and support efficient querying of historical records. These relationships allow telemetry records to be linked with events, alarms, predictive models, firmware operations, and control actions.

The primary database relationships are summarized in Table 9.

Table 9. Database relationships used within the SCC platform.

Relationship | Description
events.telemetry_id -> telemetry.id | Links an event to the telemetry sample that produced it
alarms.telemetry_id -> telemetry.id | Links an alarm to the telemetry sample that triggered it
ml_predictions.telemetry_id -> telemetry.id | Links ML predictions to the source telemetry sample
firmware_update_events.device_id -> firmware_devices.device_id | Links firmware events to a firmware device
firmware_commands.artifact_id -> firmware_artifacts.id | Links firmware commands to uploaded firmware artifacts

Table 9. Database relationships used within the SCC platform.

## 6.5. Data Indexing Strategy

Database indexes are applied to frequently queried fields to improve query performance for dashboard visualization, historical analysis, alarm investigation, and device monitoring. Indexed columns are selected based on expected filtering and retrieval operations.

Column | Purpose
created_at | Time-series queries and trend analysis
site_id | Site-level filtering
rig_id | Rig-level filtering
device_id | Device history and device-specific searches
event | Event analysis and diagnostics
hard_kill | Safety event investigation

Table 10. Database indexing strategy.

## 6.6. Data Retention Policy

A structured data-retention policy is recommended to balance long-term analytical value with database storage requirements. Raw telemetry data are retained for operational monitoring, model training, and fault analysis, while summary records and critical system events are preserved for long-term historical reference.

The recommended retention policy is summarized in Table 11.

Data Type | Retention
Raw telemetry | 30 to 90 days
Events and alarms | 1 year
Pump-cycle summaries | Long-term retention
ML predictions and MPC recommendations | 90 days
MQTT message logs | 7 to 30 days
Firmware update events | Long-term retention

Table 11. Recommended database retention policy.

To ensure data integrity and disaster recovery capability, database backups should be performed on a regular schedule using PostgreSQL backup utilities. For production deployments, daily database backups and weekly archived snapshots are recommended. Additional off-site backup storage may be implemented for enhanced system resilience and long-term record preservation.

# 7. Control System Design

## 7.1. Control Objectives

The SCC platform is designed to regulate solution temperature during stress-corrosion-cracking (SCC) testing while maintaining safe and stable operation during heating, fluid circulation, and long-duration experiments. The control system combines closed-loop temperature regulation, pump-aware compensation, and firmware-level safety mechanisms to ensure reliable operation under varying thermal conditions.

The primary control objectives are summarized in Table 12.

Objective | Description
Maintain setpoint temperature | Control the heater output to reach and hold the target bath temperature.
Prevent overheating | Disable heating when the temperature approaches unsafe limits.
Minimize thermal oscillation | Use PID control and ramped setpoints to reduce overshoot and unstable cycling.
Compensate for pump disturbance | Add heater bias before and during pump operation to reduce temperature drop.
Ensure safe operation | Apply heater lockout, hard-kill logic, and runtime limits in firmware.

Table 12. Control objectives implemented within the SCC platform.

## 7.2. Current Control Architecture

The primary control loop is executed locally within the Arduino controller firmware. Temperature measurements are acquired through the NTC thermistor and used to generate heater PWM commands. The ESP32 functions as a communication gateway, forwarding telemetry and command messages between the controller and backend infrastructure. Higher-level functions, including data storage, alarm generation, machine-learning prediction, and advisory model predictive control (MPC), are executed within the backend system.

The current control architecture is summarized in Table 13.

Control Feature | Implementation
Main controller | Arduino firmware
Communication bridge | ESP32 relay
Control output | Heater PWM
Feedback input | Temperature sensor through ADC
Control interval | 700 ms
Final setpoint | 125.00 °C
Heater PWM maximum | 200
Hard-kill temperature | 130.00 °C
Heater lockout high threshold | 128.50 °C
Heater lockout reset threshold | 126.50 °C

Table 13. SCC control system configuration.

This architecture ensures that critical control and safety functions remain operational even if communication with the backend is interrupted.

## 7.3. Control Modes

The controller operates as a finite-state system consisting of multiple control modes that support autotuning, temperature regulation, and safety management. During startup, the controller performs relay-based autotuning to estimate PID parameters. Once tuning is completed, the controller transitions to PID-based operation and maintains the target process temperature.

The available control modes are summarized in Table 14.

Mode | Description
Autotune warmup | Heater warms the system until it reaches the autotune region.
Autotune relay | Relay cycling is used to estimate PID tuning parameters.
PID ramp | The active setpoint ramps gradually from the autotune target to the final setpoint.
PID hold | The controller holds the final setpoint using PID control.
Safety override | Heating is disabled during hard kill, manual kill, or heater lockout conditions.

Table 14. Controller operating modes.

The controller automatically transitions between modes based on measured temperature, tuning completion status, and safety conditions.

## 7.4. Safety Logic

Safety functions are implemented directly within the controller firmware to ensure protection independent of the database, dashboard, network connection, machine-learning models, or backend services. Firmware-level protection guarantees that unsafe operating conditions result in immediate corrective action regardless of external system status.

The implemented safety mechanisms are summarized in Table 15.

Safety Function | Trigger | Action
Heater lockout | Temperature >= 128.50 °C | Heater output disabled
Lockout reset | Temperature <= 126.50 °C | Heater may resume
Hard kill | Temperature >= 130.00 °C | Heater and pump are disabled
Manual kill | Operator or external safety input | Control recommendation forced to zero
Runtime limit | 96 hours | Heater and pump disabled

Table 15. Firmware safety functions.

The machine-learning and MPC systems operate exclusively in an advisory capacity and shall not be considered part of the primary safety layer.

## 7.5. Pump Aware Compensation.

Pump operation introduces a predictable thermal disturbance by circulating cooler fluid through the test system. To reduce temperature excursions caused by pumping events, the controller applies anticipatory heater bias both before and during pump operation.

The pump compensation parameters are summarized in Table 16.

Parameter | Value | Description
Pump period | 30000 ms | Pump cycle interval
Pump on time | 1000 ms | Pump active duration
Pre-bias window | 5000 ms | Heater bias starts before pump activation
Pre-bias PWM | +18 | Extra heater PWM before pump operation
Pump-on bias PWM | +28 | Extra heater PWM while pump is running

Table 16. Pump-aware compensation settings.

To reduce integral windup caused by predictable disturbances, the PID integrator is temporarily frozen while the pump is active.

## 7.6. Advisory Model Predictive Control (MPC)

An advisory Model Predictive Control (MPC) module is implemented within the backend architecture to evaluate future control actions and provide operator guidance. The MPC module does not directly control the heater; instead, it evaluates candidate heater PWM values and recommends an optimal action based on predicted thermal response.

Current MPC Status: Advisory Only

Future MPC Status: Closed-Loop Control Following Validation and Safety Review

The current MPC implementation is summarized in Table 17.

MPC Feature | Description
Candidate PWM values | 0, 64, 128, 184, 220, 255
Prediction horizon | 5 seconds
Model source | `best_model_5s.joblib` if available
Fallback behavior | Uses a simple predictor when no ML model exists
Safety override | Recommends PWM 0 during hard kill, manual kill, or heater lockout

Table 17. Advisory MPC configuration

The MPC cost function minimizes temperature error while penalizing excessive control effort and abrupt changes in heater output:

cost = (predicted_(temp) -setpoint_c )^2 +0.0005*pwm^2 +0.05*(pwm - previous_(pwm) )²

## 7.7. Machine Learning Roadmap

Model source: best_model_5s.joblib if available, generated using Scikit-learn and XGBoost model pipelines [11,12]. ML models provide temperature forecasting and anomaly detection capabilities that support process monitoring and future control-system enhancements. All ML outputs are advisory and do not override firmware-level safety protections.

Planned ML applications are summarized in Table 18.

Application | Purpose
Process Prediction | Forecast future process temperatures over short time horizons
Fault Detection | Identify abnormal heater, pump, or sensor behavior
Anomaly Detection | Detect unusual telemetry patterns during operation
Predictive Maintenance | Estimate equipment degradation using historical trends
MPC Support | Provide future temperature predictions for advisory MPC calculations

Table 18. Machine-learning applications within the SCC platform.

Current prediction horizons include short-term forecasts of +1 s, +5 s, and +10 s when trained models are available. Future development will focus on model validation, uncertainty quantification, adaptive control integration, and eventual deployment of closed-loop predictive control strategies.

# 8. Safety Analysis

The SCC control platform is designed so safety-critical decisions remain on the hardware side of the system. The Arduino controller and electrical interlocks own heater and pump shutdown behavior. The ESP32, Flask backend, database, HMI, ML model, and MPC service provide communication, monitoring, logging, alarms, and advisory recommendations only.

Backend alarms and dashboard notifications improve operator visibility, but they are not the primary protection layer. The rig must remain safe if the network, MQTT broker, database, server, HMI, ML model, or MPC endpoint fails.

## 8.1. Hazards

A hazard assessment was performed to identify potential failure modes, their consequences, and existing mitigation measures. The identified hazards are summarized in Table 19.

Hazard | Potential Consequence | Existing Mitigation
Bath overheating | Equipment damage, accelerated corrosion, unsafe test conditions, or operator burn hazard | Firmware heater lockout at 128.5 °C, hard kill at 130.0 °C, heater PWM limiting, and backend high-temperature alarms
Thermistor failure or invalid ADC reading | Incorrect temperature feedback resulting in uncontrolled heating | Sensor fault detection, ADC validation checks, heater shutdown, pump shutdown, lockout activation, and alarm generation
Pump failure or blocked flow | Poor solution circulation, invalid test results, and delayed thermal recovery | Pump telemetry monitoring, recovery-time analysis, and backend alarm generation
Pump operation without sufficient thermal headroom | Excessive temperature drop below operating conditions | Temperature-gated pump operation with configurable upper and lower thresholds
Heater output failure or excessive PWM command | Thermal runaway and equipment damage | Firmware lockout logic, hard-kill protection, PWM limiting, and recommended independent power isolation
Manual emergency shutdown | Delayed operator response during abnormal conditions | Manual kill command and provision for physical emergency-stop hardware
Network, MQTT, server, database, or HMI failure | Loss of monitoring, alarms, and remote control capability | Local firmware continues operation independently of backend services
ML or MPC recommendation error | Unsafe recommendation if treated as direct control action | MPC remains advisory only and cannot override firmware safety logic
Firmware update interruption | Uncertain controller state during firmware update operations | OTA preparation disables heater and motor outputs before reset
Excessive runtime or unattended operation | Continued operation beyond intended test duration | Firmware runtime limit and automatic shutdown functionality

Table 19. Hazard analysis and mitigation measures.

## 8.2. Safety Features

Multiple independent safety mechanisms are implemented within the SCC platform to prevent unsafe operation and reduce risk associated with hardware faults, software faults, and operator error.

The primary safety functions are summarized below:

- Heater Lockout: Heater output is disabled when measured temperature reaches 128.5 °C. Heating may resume only after temperature decreases below 126.5 °C.
- Hard Kill Protection: At 130.0 °C, the controller immediately disables heater and pump outputs, clears control commands, resets the PID integrator, activates lockout status, and generates a hard-kill event.
- Manual Kill Function: Operator-issued kill commands immediately disable heater and pump outputs and prevent further actuation until reset.
- Sensor Fault Detection: Invalid ADC values and thermistor fault conditions automatically disable all outputs and generate a fault event.
- Safe Startup Sequence: Heater and motor outputs remain disabled during initialization until controller state validation is complete.
- Pump Temperature Gating: Pump operation is permitted only within an approved temperature operating window.
- PWM Limiting: Heater PWM commands are constrained to a configurable maximum value to prevent excessive power output.
- PID Windup Protection: Integral accumulation is reset during lockout, hard-kill, manual-kill, and sensor-fault conditions.
- Safe OTA Preparation: Firmware update procedures disable all outputs before initiating reset or programming operations.
- Alarm Logging and Audit Trail: Critical safety events are recorded within the database and displayed through the HMI.
- Advisory-Only MPC: Model-based recommendations are prevented from overriding firmware safety states

## 8.3. Emergency Shutdown Procedure

In the event of abnormal operation or a hazardous condition, the following emergency shutdown procedure shall be performed:

1. Emergency shutdown order should issue a manual kill before disconnecting power only if HMI is available; otherwise, disconnect power first.
2. Disconnect the power
3. Verify that heater PWM output is zero and heater power is electrically isolated.
4. Verify that all pump and motor outputs are disabled.
5. Allow the bath temperature to decrease below the lockout reset threshold.
6. Record the event, including timestamp, measured temperature, active alarms, and operator actions.
7. Inspect the heater assembly, thermistor, pump system, power electronics, and enclosure for damage or abnormal conditions.
8. Restart operation only after the root cause has been identified and corrective actions have been completed.

## 8.4. Safety verification Tests

Safety functions shall be validated through functional testing before deployment. Verification tests are summarized in Table 20.

Safety Function | Test Method | Expected Result
Safe Startup | Power cycle controller while monitoring outputs | Outputs remain disabled during initialization
Heater Lockout | Raise temperature to 128.5 °C | Heater output disabled and lockout activated
Lockout Recovery | Reduce temperature below 126.5 °C | Lockout clears and normal operation resumes
Hard Kill | Simulate temperature ≥ 130.0 °C | Heater and pump disabled; hard-kill event generated
Sensor Fault Detection | Simulate open-circuit or short-circuit thermistor | Outputs disabled and fault event generated
Manual Kill | Issue kill command through communication interface | Heater and pump immediately disabled
Pump Temperature Gating | Test operation at threshold temperatures | Pump operates only within permitted temperature range
Runtime Limit | Simulate 96-hour runtime condition | Heater and pump automatically disabled
Backend Alarm Path | Inject alarm-triggering telemetry data | Correct alarm generation and logging
MPC Safety Override | Request recommendation during safety event | Recommended PWM returns zero

Table 20. Safety verification tests.

## 8.5. Residual Risk and Recommendation

Although multiple layers of protection are implemented, certain residual risks remain and should be addressed prior to unattended or production operation.

- Installation of a physical emergency-stop device or independent power disconnect is strongly recommended.
- Thermistor calibration and fault-detection thresholds should be validated experimentally using open-circuit, short-circuit, and elevated-temperature conditions.
- Heater MOSFET, relay, or power-stage failures may bypass software control; independent over-temperature protection and fused power isolation should be considered.
- Network failures eliminate remote visibility and alarm reporting; local indicators and periodic operator inspection remain necessary.
- OTA firmware update functionality should remain restricted until complete hardware validation has been performed.
- Any future implementation of closed-loop MPC control shall require a dedicated safety review, cybersecurity review, and verification that firmware safety mechanisms cannot be bypassed.

The safety architecture implemented within the SCC platform ensures that hazardous conditions are mitigated through local firmware protection mechanisms while maintaining operational visibility through backend monitoring, alarm management, and data logging services.

# 9. Verification and Validation

## 9.1. Verification and Validation Overview

Verification and validation activities were developed to evaluate the functionality, reliability, and safety of the SCC platform. Verification focuses on confirming that individual software modules, firmware functions, communication interfaces, and safety mechanisms perform according to their design requirements. Validation focuses on demonstrating that integrated subsystems operate correctly when deployed as a complete platform.

The SCC platform repository currently contains automated unit tests covering firmware logic, ESP32 relay parsing, backend telemetry processing, alarm generation, firmware management functions, API authentication, and advisory MPC safety behavior. In addition, the repository includes manual integration procedures for telemetry-path validation and dedicated hardware test projects for thermistor, heater, and motor verification.

The verification matrices presented in this section include only tests and validation procedures that currently exist within the repository. Planned activities that have not yet been implemented, including dashboard automation testing, heartbeat monitoring validation, long-duration endurance testing, and full commissioning activities, are excluded from the formal verification record and are identified separately as future work.

## 9.2. Unit Tests

Unit testing is used to verify individual firmware and software functions in isolation before subsystem integration. These tests evaluate temperature measurement, safety logic, pump control, telemetry generation, communication parsing, backend processing, firmware management, and MPC advisory functions.

The implemented unit test matrix is summarized in Table 21.

Test ID | Description | Expected Result | Status
UT-001 | Temperature conversion and ADC calibration | ADC values are converted to expected temperature values using the calibrated transfer function | Implemented
UT-002 | ADC sensor fault detection | Open-circuit and short-circuit ADC rail values are detected with recovery hysteresis | Implemented
UT-003 | Pump temperature gating | Pump permission enables only with thermal headroom and disables at low or high temperature limits | Implemented
UT-004 | Pump PWM timing | Pump startup kick, run PWM, and off timing follow the configured motor cycle | Implemented
UT-005 | Motor timer and heater pre-bias logic | Motor cycle phase and heater bias windows are calculated correctly | Implemented
UT-006 | Autotune and PID state logic | Autotune transitions, timeout behavior, PID first-sample behavior, ramp completion, and lockout output suppression work as expected | Implemented
UT-007 | Telemetry CSV schema | Telemetry header column count and column order match the expected schema | Implemented
UT-008 | Bootloader entry command parsing | Supported bootloader preparation commands are accepted and unrelated commands are rejected | Implemented
UT-009 | ESP32 relay CSV parsing | Arduino CSV telemetry rows are parsed into the relay snapshot fields correctly | Implemented
UT-010 | ESP32 relay backend command parsing | Supported backend command types are parsed and unsupported commands are rejected | Implemented
UT-011 | Backend telemetry parser | Headerless and header-based CSV telemetry rows are parsed and invalid rows are rejected | Implemented
UT-012 | Backend alarm rules | Hard kill, manual kill, heater lockout, sensor fault, high temperature, slow recovery, and excessive cooling alarms are generated correctly | Implemented
UT-013 | Backend API authentication | Protected telemetry write endpoints reject missing keys and accept valid API key formats | Implemented
UT-014 | Firmware API validation and command queue | ESP32 and Arduino firmware file types are validated and queued commands can be acknowledged | Implemented
UT-015 | MPC safety override | MPC recommendations return zero PWM during hard kill, manual kill, or heater lockout states | Implemented

Table 21. Implemented unit tests for SCC firmware, ESP32 relay services, backend services, and MPC logic.

Successful execution of these tests verifies that the individual software and firmware components operate according to their intended design requirements and interface specifications.

## 9.3. Integration and Hardware Validation Procedures

Integration testing verifies communication and interoperability between embedded controllers, communication services, backend infrastructure, and database storage systems. Hardware validation procedures are used to confirm operation of physical components, including temperature sensing, heater control, and pump actuation.

The integration and hardware validation procedures currently implemented within the repository are summarized in Table 22.

Test ID | Description | Expected Result | Status
IT-001 | Arduino telemetry to ESP32 relay parsing | ESP32 receives deterministic Arduino CSV rows and parses them with the relay core parser | Manual procedure defined
IT-002 | ESP32 telemetry relay to Flask API | ESP32 posts parsed telemetry JSON to the Flask telemetry endpoint | Manual procedure defined
IT-003 | Flask telemetry ingestion to PostgreSQL | Stored PostgreSQL rows match the source Arduino CSV fixture | Manual verifier implemented
IT-004 | End-to-end telemetry pipeline | Data propagate from Arduino test firmware through ESP32 and Flask into PostgreSQL | Manual procedure defined
IT-005 | Backend-only telemetry pipeline smoke test | Sample CSV rows are posted directly to Flask and verified against PostgreSQL without hardware | Scripted verifier implemented
IT-006 | Standalone NTC temperature readout | Arduino reads thermistor ADC values and prints live temperature CSV rows | Manual hardware test project defined
IT-007 | Standalone heater control test | Arduino heater test accepts start/stop commands, limits PWM, and reports hard-kill status | Manual hardware test project defined
IT-008 | Standalone motor output test | Arduino motor test accepts start/stop commands and reports PWM output state | Manual hardware test project defined

Table 22. Implemented integration tests and hardware validation procedures.

These procedures provide verification of data flow through the telemetry pipeline, communication between hardware and software subsystems, database storage integrity, and operation of critical hardware components. Together, they establish confidence that the individual subsystems can function as an integrated SCC platform.

## 9.4. Current Verification Coverage Gaps

Although significant verification coverage has been implemented, several system-level validation activities remain outside the current repository scope. These items represent future verification work that should be completed before deployment in a production or long-duration testing environment.

The repository does not currently include automated verification for dashboard live-update functionality, MQTT broker transport validation, heartbeat and offline-device detection, complete HMI-to-controller manual-kill routing, or full system commissioning and endurance testing. These activities should remain classified as future validation tasks until formal test procedures, execution records, and acceptance criteria have been developed.

Future verification efforts should also include extended-duration operational testing, failure-recovery testing, network-loss testing, and final acceptance testing of the fully integrated SCC platform.

## 9.5. Verification Summary

The SCC platform currently includes implemented verification activities covering firmware control logic, safety mechanisms, telemetry generation, communication parsing, backend processing, firmware management, and advisory MPC behavior. Additional integration procedures and standalone hardware validation projects have been developed to support verification of communication pathways and physical hardware operation.

The existing verification framework provides a foundation for future system-level validation and commissioning activities while demonstrating that the major software, firmware, and hardware subsystems have defined verification procedures and measurable acceptance criteria.

# 10. Deployment Guide

## 10.1. Deployment Overview

The SCC platform is deployed using a containerized architecture based on Docker and Docker Compose [6] consisting of a Flask backend, React Human–Machine Interface (HMI), PostgreSQL database, MQTT broker, and optional Cloudflare Tunnel service. Docker Compose is used to simplify deployment and ensure consistent configuration across development and production environments.

The deployment architecture supports local operation on a single workstation or distributed deployment across multiple networked systems. The ESP32 communication gateway publishes telemetry data through MQTT, while backend services process, store, and visualize operational data.

## 10.2. Server Requirements

The deployment server must provide sufficient computing resources to support the backend API, database services, MQTT communication, dashboard visualization, and future machine-learning workloads.

Operating System: Ubuntu Server Lite

Processor: Intel NUC

Memory: 4 GB RAM

Storage: 128GB

Network: The deployment server must be reachable by the ESP32 communication gateway. Required ports include:

Service | Port
MQTT Broker | 1883
Backend API | 5050
Frontend Dashboard | 5173
PostgreSQL | 5432

Table 23. Network Ports

Software Requirements:

- Docker Engine or Docker Desktop
- Docker Compose
- Python 3.11 (non-Docker deployment)
- Node.js 22 (non-Docker deployment)
- PostgreSQL
- Eclipse Mosquitto MQTT Broker

## 10.3. Containerized Services

The SCC platform is composed of multiple Docker services that provide communication, data storage, visualization, firmware management, and predictive analytics capabilities.

Service | Image or Build Source | Port | Purpose
Backend | backend/Dockerfile using Python 3.11-slim | 5050:5000 | Runs the Flask API, MQTT subscriber, telemetry parser, alarm engine, ML prediction services, MPC advisory logic, and firmware management APIs
Frontend | node:22-alpine | 5173:5173 | Provides the React/Vite HMI dashboard for monitoring, alarms, trends, settings, firmware management, and analytics
PostgreSQL | postgres:16 | 5432:5432 | Stores telemetry, alarms, events, pump-cycle records, predictions, commands, and configuration data
MQTT Broker | eclipse-mosquitto:2 | 1883:1883, 9001:9001 | Provides MQTT and MQTT-over-WebSocket communication services
Cloudflare Tunnel | cloudflare/cloudflared:latest | Outbound Tunnel | Optional secure remote-access service

Table 24. Docker services used within the SCC platform deployment.

## 10.4. Deployment Procedure

The following procedure is used to deploy the SCC platform using Docker Compose.

Step 1 – Obtain the Source Repository

git clone <repository-url>

cd scc-control-platform

Step 2 – Create the Environment Configuration File

cp .env.example .env

Step 3 – Configure Environment Variables

The minimum required configuration is shown below.

API_WRITE_KEY=<shared-write-key-for-backend-and-dashboard>

CORS_ORIGINS=http://localhost:5173

PUBLIC_BASE_URL=http://localhost:5050

MQTT_HOST=mosquitto

MQTT_PORT=1883

MQTT_BASE_TOPIC=scc

If email notifications are enabled, SMTP configuration parameters must also be defined.

Step 4 – Start Platform Services

docker compose up --build

Step 5 – Verify Service Status

docker compose ps

Step 6 – Verify Application Access

Backend API: http://localhost:5050

Frontend HMI: http://localhost:5173

PostgreSQL: localhost:5432

MQTT Broker: localhost:1883

Step 7 – Configure ESP32 Communication Gateway

Update the ESP32 firmware configuration to match the deployment environment.

#define MQTT_BROKER_URI "mqtt://<server-lan-ip>:1883"

#define MQTT_BASE_TOPIC "scc"

#define MQTT_SITE_ID "site-01"

#define MQTT_RIG_ID "rig-01"

#define MQTT_DEVICE_ID "esp32-relay-01"

Step 8 – Verify Telemetry Communication

Confirm that telemetry messages are received by the backend and appear within the dashboard.

GET http://localhost:5050/api/latest

Step 9 – Execute Verification Procedures

Prior to operation, execute available automated verification tests.

pytest backend/tests

pio test -d firmware/arduino/SCC-V1.4 -e native

pio test -d firmware/esp32/ESP32-Relay -e native

Step 10 – Configure Optional Remote Access

For remote access deployments, configure the Cloudflare Tunnel token to enable secure external access without direct port exposure [13] within the environment configuration file.

CLOUDFLARE_TUNNEL_TOKEN=<cloudflare-token>

After deployment, verify that public endpoints correctly route traffic to the backend API and HMI dashboard.

## 10.5. Post-Deployment Verification

Following deployment, a series of checks should be performed to confirm proper system operation.

Check | Expected Result
Backend Health | Backend responds successfully on http://localhost:5050
Dashboard Access | HMI dashboard loads on http://localhost:5173
Database Startup | PostgreSQL container reports healthy status
MQTT Connectivity | ESP32 successfully connects to the MQTT broker
Telemetry Reception | /api/latest returns current telemetry data
Alarm Functionality | Active alarms appear within API responses and dashboard views
Manual Kill Command | Authenticated kill commands can be issued successfully
Data Persistence | PostgreSQL data remain available following container restart

Table 25. Post-deployment verification checklist.

Successful completion of the post-deployment verification checklist indicates that the SCC platform has been deployed correctly and is ready for hardware integration, system validation, and operational testing.

# 11. Operations Guide

## 11.1. Startup Procedure

Before operation, the SCC platform shall be inspected to verify that all mechanical, electrical, thermal, and communication systems are functioning correctly. The startup procedure ensures that the specimen, heating cell, circulation system, sensors, and control electronics are prepared for safe operation before heating is enabled.

The startup procedure shall be performed in the order listed below.

1. Wear personal protective equipment (PPE): Gloves and Safety glasses.
2. Mount the test specimen securely within the test fixture.
3. Apply RTV sealant around the copper cell sealing surfaces as required.
4. Install and secure the copper heating cell.
5. Connect the pump outlet tubing to the copper cell.
6. Connect the exhaust tubing to the copper cell.
7. Verify that the MgCl₂ reservoir contains sufficient solution for the planned test duration.
8. Verify that the pump intake tubing remains fully submerged below the fluid surface.
9. Verify thermistor and temperature sensor connections.
10. Verify heater wiring and heater cartridge installation.
11. Verify all control electronics, power connections, and communication cables.
12. Apply power to the SCC platform.
13. Verify network connectivity between the ESP32 gateway and backend services.
14. Allow the control system to complete initialization and startup checks.
15. Verify dashboard status indicators and confirm receipt of live telemetry.

Successful completion of the startup procedure indicates that the SCC platform is ready for operation.

## 11.2. Corrosive Medium Preparation and Handling

The SCC platform utilizes a magnesium chloride (MgCl₂) solution as the corrosive medium for stress-corrosion-cracking experiments. Proper preparation of the solution is required to ensure repeatable test conditions and consistent corrosion behavior.

Solution Composition

The standard corrosion solution used for SCC testing is summarized in Table 26.

Parameter | Value
Chemical | Magnesium Chloride Hexahydrate (MgCl₂·6H₂O)
Solution Concentration | 30 wt.% MgCl₂
MgCl₂·6H₂O Mass | 500 g
Deionized Water Volume | 280 mL
Typical Operating Temperature | 125 °C

Table 26. Standard MgCl₂ corrosion solution.

Preparation Procedure

1. Wear personal protective equipment (PPE): ideally, safety glasses, gloves, and a mask.
2. Verify that a clean mixing container is available.
3. Measure 280 mL of deionized (DI) water.
4. Add 500 g of magnesium chloride hexahydrate (MgCl₂·6H₂O) to the container.
5. Slowly add the DI water while stirring continuously.
6. Continue mixing until all visible solids are dissolved and a uniform solution is obtained.
7. Allow the solution to stabilize before transferring it to the SCC reservoir.
8. Verify that the reservoir contains sufficient solution volume before beginning operation.

## 11.3. Operator Responsibilities and Monitoring Requirements

During operation, the operator is responsible for maintaining safe operating conditions, monitoring system performance, and responding to alarms or abnormal conditions.

### Operator Responsibilities

- Confirm that the SCC rig is physically safe to operate before enabling heat or pump activity.
- Keep the HMI dashboard open throughout testing and verify that telemetry updates continuously.
- Monitor bath temperature, temperature error, heater PWM, pump status, and controller operating mode.
- Verify that the system remains within the intended operating temperature range.
- Confirm that heater lockout, manual kill, and hard-kill indicators remain inactive during normal operation.
- Verify that pump cycles occur only when sufficient thermal headroom is available.
- Review active alarms and event timeline entries throughout each operating session.
- Treat machine-learning predictions and MPC recommendations as advisory information only.
- Record abnormal behavior, alarms, operator actions, and shutdown events in the test log.
- Immediately stop testing if unsafe operating conditions are observed.

### Monitoring Requirements

The following parameters shall be monitored during active operation:

- Process temperature, setpoint temperature, and temperature error.
- Heater PWM command and heater operating state.
- Pump status, motor PWM, pump recovery time, and pump-cycle temperature drop.
- Active alarm status and alarm history.
- Event timeline entries, including pump start, pump stop, pump recovery, hard-kill, and sensor-fault events.
- MQTT connectivity and dashboard update status.
- Database logging status and telemetry history availability.

Operators shall remain in the vicinity of the test system during active heating unless approved unattended-operation procedures and independent physical safety systems are in place.

Any abnormal noise, fluid leakage, overheating, unexpected pump behavior, unusual odor, electrical fault indication, or loss of telemetry shall require immediate investigation and possible shutdown.

## 11.4. Alarm Response Procedures

The SCC platform generates alarms to notify operators of abnormal operating conditions. Critical alarms require immediate corrective action, while warning alarms require increased monitoring and investigation.

Alarm | Severity | Operator Response
HARD_KILL | Critical | Treat as an emergency shutdown. Verify heater PWM is zero, verify pump output is disabled, allow cooling, inspect hardware, and determine root cause before restart.
MANUAL_KILL | Critical | Confirm shutdown was intentional. Maintain disabled state until inspection is complete and restart conditions are met.
SENSOR_FAULT | Critical | Stop operation, inspect thermistor wiring and ADC input, verify temperature independently if possible, and restart only after valid telemetry is restored.
HIGH_TEMP_CRITICAL | Critical | Disable heating immediately, allow cooling, and inspect heater and temperature-control hardware.
HEATER_LOCKOUT | Warning | Continue monitoring while heating remains disabled. Resume operation only after temperature falls below the reset threshold.
HIGH_TEMP_WARNING | Warning | Monitor temperature trend and heater output closely. Prepare for shutdown if temperature continues increasing.
SLOW_RECOVERY | Warning | Inspect pump operation, fluid flow path, mixing performance, and thermal recovery characteristics.
EXCESSIVE_PUMP_COOLING | Warning | Verify pump timing, flow rate, solution temperature, and compensation settings.

Table 27. Alarm response procedures.

If any critical alarm occurs, operator safety and equipment protection shall take priority over test completion or data collection. Testing shall remain suspended until the root cause has been identified and corrective action has been completed.

## 11.5. Shutdown Procedure

The SCC platform shall be shut down in a controlled manner to prevent equipment damage, fluid spills, and unnecessary exposure to heated MgCl₂ solution.

The shutdown procedure shall be performed in the order listed below.

1. Wear all required personal protective equipment (PPE).
2. Issue the manual kill command through the HMI or controller interface.
3. Disconnect power from the SCC platform.
4. Disconnect the intake tubing from the pump and allow residual solution to drain.
5. Disconnect the pump outlet tubing from the copper cell and return residual solution to the reservoir.
6. Remove the copper cell assembly from the specimen.
7. Remove the test specimen from the fixture.
8. Clean the copper cell, tubing, specimen, and work area.
9. Inspect the system for corrosion, leaks, damaged wiring, or abnormal wear.
10. Record test completion details, observations, alarms, and maintenance actions in the test log.

Successful completion of the shutdown procedure returns the SCC platform to a safe, de-energized condition suitable for storage, maintenance, or preparation for the next test.

# 12. Maintenance Manual

## 12.1. Maintenance Overview

Routine maintenance is required to ensure reliable operation of the SCC platform and to minimize the risk of equipment failure, inaccurate measurements, communication interruptions, and unsafe operating conditions. Maintenance activities are divided into preventive maintenance and corrective maintenance. Preventive maintenance consists of scheduled inspections and verification activities intended to identify potential issues before failure occurs. Corrective maintenance is performed in response to alarms, faults, abnormal system behavior, or equipment malfunction.

All maintenance activities should be recorded in the system maintenance log, including inspection dates, observations, corrective actions, replacement parts, and personnel performing the work.

## 12.2. Preventive Maintenance

Preventive maintenance shall be performed according to the schedule shown in Table 27. These activities are intended to verify proper operation of sensing, heating, pumping, communication, and data-management systems before faults occur.

Item | Frequency
Temperature sensor inspection | Daily
Heater and pump status check | Daily
SCC test cell inspection | Daily
Wiring and connector inspection | Weekly
MQTT/backend connectivity check | Weekly
Database backup verification | Monthly
Firmware and configuration backup | Monthly
Alarm and manual kill function check | Monthly

Table 28. Preventive maintenance schedule.

Daily Inspection Requirements

- Inspect the thermistor and sensor wiring for damage, corrosion, or loose connections.
- Verify proper heater operation and confirm normal heating response.
- Verify pump operation and check for leaks, blockage, or abnormal noise.
- Inspect the SCC test cell for corrosion, contamination, fluid leakage, or physical damage.
- Verify that telemetry data are being reported correctly through the dashboard.

Weekly Inspection Requirements

The following items should be verified at least once per week:

- Inspect all electrical wiring, connectors, and terminal blocks.
- Verify MQTT communication between the ESP32 relay and backend services.
- Review alarm history for recurring faults or abnormal trends.
- Inspect tubing and fluid pathways for signs of wear, clogging, or degradation.

Monthly Inspection Requirements

The following items should be verified monthly:

- Confirm successful PostgreSQL database backups.
- Create backups of firmware images and system configuration files.
- Verify operation of manual kill, heater lockout, and hard-kill safety functions.
- Review system logs for persistent alarms, communication issues, or abnormal operating conditions.

## 12.3. Corrective Maintenance

Corrective maintenance shall be performed whenever a fault, alarm condition, communication failure, hardware malfunction, or abnormal operating condition is observed. The objective of corrective maintenance is to identify the root cause of the issue, restore normal operation, and prevent recurrence.

The recommended corrective actions for common fault conditions are summarized in Table 28.

Fault Condition | Corrective Action
Sensor fault | Inspect thermistor wiring, verify ADC readings, replace sensor if needed
Heater not responding | Check heater wiring, MOSFET/relay, power supply, PWM output, and firmware state
Pump not operating | Inspect pump wiring, motor driver, tubing, flow path, and motor PWM output
Excessive temperature | Stop operation, verify heater output is off, inspect sensor accuracy and heater control circuit
Telemetry loss | Check ESP32 power, Wi-Fi/MQTT connection, backend service, and broker status
Database logging failure | Check PostgreSQL container, disk space, backend logs, and database connection string
Dashboard not updating | Check backend API, frontend service, network connection, and browser console errors

Table 29. Corrective maintenance procedures.

## 12.4. Component Replacement Guidelines

When replacing components, power shall be removed from the system, and all heated surfaces shall be allowed to cool to a safe handling temperature. Replacement components shall meet the original design specifications and shall be verified through functional testing before returning the system to service.

The following components are considered field-replaceable:

- NTC thermistor temperature sensor
- Cartridge heater
- Pump and pump tubing
- ESP32 communication module
- Wiring harnesses and electrical connectors
- Power switching components, including relays and MOSFETs

Following replacement, a startup inspection and verification test shall be performed to confirm correct operation.

## 12.5. Maintenance Safety Considerations

Maintenance activities shall be performed only when the system is in a safe, de-energized condition. Operators shall wear appropriate personal protective equipment when handling heated components, corrosive solutions, electrical systems, or contaminated hardware.

Before performing maintenance:

1. Issue a manual kill command if the system is operational.
2. Disconnect system power.
3. Allow the copper heating cell and associated hardware to cool.
4. Drain or isolate MgCl₂ solution if fluid-handling components will be serviced.
5. Verify that all heater and pump outputs are de-energized.
6. Follow applicable laboratory safety procedures for chemical handling and disposal.

# 13. Troubleshooting Guide

## 13.1. Troubleshooting Overview

This section guides diagnosing and correcting common hardware, firmware, communication, database, and operational issues that may occur during SCC platform operation. Troubleshooting should be performed systematically, beginning with verification of safety conditions, power availability, sensor status, and communication connectivity before attempting more advanced diagnostics.

When investigating faults, operators should review active alarms, telemetry values, event logs, backend logs, and dashboard status indicators. If a critical alarm such as HARD_KILL, MANUAL_KILL, or SENSOR_FAULT is active, the system shall remain in a safe state until the root cause has been identified and corrected.

The troubleshooting matrix is summarized in Table 29

Issue | Possible Cause | Corrective Action
No temperature data | Thermistor disconnected, ADC input fault, Arduino not running, or ESP32 not forwarding telemetry | Inspect thermistor wiring, verify Arduino serial output, check ESP32 power, and confirm telemetry reaches the backend
Temperature value is unrealistic | Sensor calibration error, loose thermistor connection, ADC rail reading, or damaged sensor | Check ADC value, inspect wiring, compare with an independent thermometer, replace sensor if needed, and recalibrate
SENSOR_FAULT alarm active | Open-circuit or short-circuit sensor condition, missing temperature field, or invalid ADC data | Stop operation, inspect sensor circuit, restore valid readings, and restart only after the alarm clears
No MQTT data | Mosquitto broker offline, wrong broker IP, Wi-Fi issue, wrong MQTT topic, or ESP32 disconnected | Verify broker container is running, confirm ESP32 uses the server LAN IP, check Wi-Fi credentials, and confirm topic format
Backend not receiving telemetry | MQTT subscriber offline, backend container stopped, bad API key for HTTP test path, or malformed payload | Check backend logs, restart backend if needed, verify MQTT settings, and validate telemetry format
Dashboard not updating | Frontend cannot reach backend, backend API down, stale browser session, or telemetry not arriving | Open http://localhost:5050/api/latest, check frontend API URL, refresh the dashboard, and verify backend/container status
PostgreSQL logging failure | Database container unhealthy, wrong DATABASE_URL, schema not initialized, or disk full | Check docker compose ps, inspect database logs, verify connection string, confirm free disk space, and restart services if required
Heater disabled | Heater lockout, hard kill, manual kill, sensor fault, temperature above setpoint, or runtime limit reached | Check active alarms and telemetry flags, verify temperature limits, clear manual kill only after inspection, and allow cooling before restart
Heater does not heat when expected | PWM output disabled, MOSFET/relay fault, power supply issue, wiring fault, or failed heater | Verify heater PWM telemetry, inspect power electronics, measure output voltage safely, and test heater circuit before operation
Temperature rising too fast | Heater control fault, stuck MOSFET/relay, sensor reading low, or excessive heater power | Stop the test, verify heater output is de-energized, inspect sensor accuracy, and check heater driver hardware
Pump not running | Pump temperature gate disabled, motor driver fault, wiring fault, pump jam, manual kill, hard kill, or runtime limit | Check pump_allowed, pump_on, and motor PWM telemetry, inspect wiring and driver, and test the pump with the standalone motor test
Excessive pump cooling | Pump dose too large, solution too cold, flow path issue, poor thermal compensation, or incorrect pump timing | Inspect pump timing, flow rate, tubing, solution temperature, and review last_pump_drop_c telemetry
Slow recovery after pump cycle | Heater underpowered, poor mixing, pump disturbance too large, or thermal model mismatch | Check heater PWM, pump recovery time, bath mixing, and pump settings before continuing the test
HEATER_LOCKOUT alarm active | Temperature reached lockout threshold or lockout remains set after a fault | Keep heater disabled, allow bath to cool below reset threshold, inspect cause, and resume only if no critical alarm remains
HARD_KILL alarm active | Temperature reached hard-kill threshold or safety shutdown was triggered | Treat as emergency shutdown, verify heater and pump outputs are off, inspect hardware, and do not restart until root cause is found
MANUAL_KILL alarm active | Operator issued emergency off command or command remains latched | Confirm shutdown state, inspect rig, then release manual kill only when safe to resume
Manual kill command not received | API write key mismatch, ESP32 command polling stopped, backend command queue issue, or network failure | Verify API_WRITE_KEY and VITE_API_WRITE_KEY, check ESP32 polling endpoint, confirm backend is reachable, and inspect command queue logs
Firmware OTA command fails | Wrong firmware file type, unreachable firmware URL, missing reset wiring, bad OTA configuration, or device offline | Verify firmware type, check PUBLIC_BASE_URL, confirm device connectivity, and keep Arduino OTA disabled unless reset/programming path is tested
Email alerts not sent | Email alerts disabled, SMTP settings missing, bad credentials, or cooldown interval active | Check ALERT_EMAIL_ENABLED, SMTP variables, backend logs, and ALERT_EMAIL_COOLDOWN_SECONDS
Cloudflare/public URL not working | Missing tunnel token, tunnel container stopped, DNS route not configured, or service origin mismatch | Set CLOUDFLARE_TUNNEL_TOKEN, check tunnel logs, verify route configuration, and confirm backend/frontend are reachable locally
Tests fail to run | Python dependencies missing, PlatformIO not installed, wrong working directory, or hardware not connected | Install dependencies, run from scc-control-platform, use the documented pytest and pio test commands, and connect required test hardware

Table 30. SCC platform troubleshooting guide.

## 13.2. Troubleshooting Workflow

When a fault occurs, troubleshooting should follow the sequence below:

1. Review active alarms displayed on the dashboard.
2. Verify that the system is in a safe operating state.
3. Confirm power availability and controller operation.
4. Verify thermistor readings and telemetry updates.
5. Check MQTT communication and backend connectivity.
6. Verify database logging and dashboard operation.
7. Review recent event logs and alarm history.
8. Inspect associated hardware components.
9. Correct the identified fault condition.
10. Perform startup verification before resuming operation.

Following a consistent troubleshooting process helps minimize downtime and reduces the likelihood of overlooking related faults.

## 13.3. Escalation Criteria

Operation shall be suspended and the system removed from service if any of the following conditions occur:

- Repeated activation of the hard-kill protection system.
- Repeated sensor-fault alarms after sensor replacement.
- Evidence of overheating, smoke, electrical arcing, or damaged wiring.
- Fluid leakage from the SCC cell, tubing, or reservoir.
- Failure of heater lockout or manual kill functions.
- Corrupted database records or persistent telemetry loss.
- Any condition that could compromise operator safety or test validity.

The system shall not be returned to service until the root cause has been identified, corrective action has been completed, and normal operation has been verified.

# 14. References

[1] MQTT.org, "MQTT Version 5.0 Specification," MQTT.org, 2019.

[2] Javan Electronics, "ESP32 DOIT DevKit V1 Technical Reference Manual," Javan Electronics.

[3] Arduino, "Arduino Uno Rev3 Technical Specifications," Arduino Documentation.

[4] PostgreSQL Global Development Group, "PostgreSQL Documentation."

[5] Pallets Projects, "Flask Documentation."

[6] Docker Inc., "Docker Documentation."

[7] Eclipse Foundation, "Eclipse Mosquitto Documentation."

[8] Python Software Foundation, "Python 3.11 Documentation."

[9] SQLAlchemy Authors, "SQLAlchemy Documentation."

[10] Socket.IO Authors, "Socket.IO Documentation."

[11] XGBoost Contributors, "XGBoost Documentation."

[12] Scikit-learn Developers, "Scikit-learn Documentation."

[13] Cloudflare Inc., "Cloudflare Tunnel Documentation."

[14] Intel Corporation, "Intel NUC Technical Product Specifications."

[15] Microchip Technology Inc., "ATmega328P Datasheet."

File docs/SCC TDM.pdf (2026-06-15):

Stainless Steel 316 Stress Corrosion Cracking System Technical Design, Operations, and Maintaince Manual Document Number: SCC-TDM-001 Revision: 0.1 Draft
Author: John Jin
Date: June 9, 2026

Revision History:
Revision | Date | Author | Description
0.1 | June 9, 2026 | John Jin | Initial Draft

## Table of Contents

## 1. Introduction

## 1.1. Purpose

The Stress Corrosion Cracking (SCC) test system is an automated control system designed to heat the specimen and pump corrosive medium, such as magnesium chloride (MgCl2), while the sample undergoes creep loading. The platform integrates embedded hardware, process control algorithms, wireless communication, database infrastructure, and data analysis into a unified architecture [1–10].

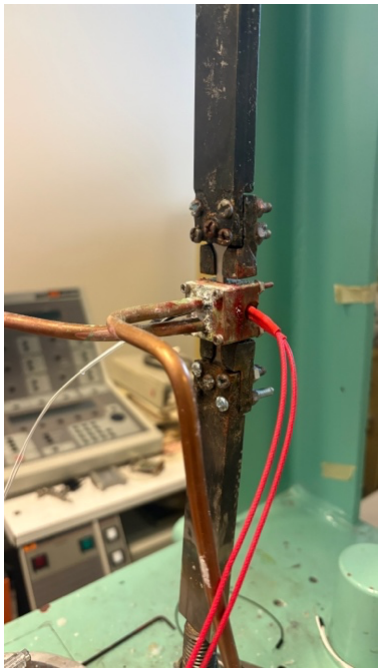
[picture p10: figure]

Fig 1. Testing setup

## 1.2. Scope

This document will include the following facets of the system:
- System architecture
- Hardware design
- Firmware design
- Backend infrastructure
- Database structure
- Control algorithms
- Safety systems
- Testing procedures
- Operational procedures

## 1.3. Objectives

The primary objectives of the SCC platform are:

### 1. Reliable process

The system must be designed to repeat the experiment process repeatedly. This process should be capable of being repeated with minimal human intervention to address any potential issues that may arise.

### 2. Reliable monitoring method

The system must be monitored with ease and reliability. All sensors must remain operational for an extended period beyond the duration of a single testing experiment.

### 3. Automated test control (temperature, pump frequency, etc.)

The PID system should be equipped with self-tuning capabilities and housed in a secure environment.

### 4. Safe heater operation

The temperature should not exceed 20 degrees Celsius above the set point or 350 degrees Celsius.

### 5. Continuous data logging

It’s important to log crucial parameters, including temperature, pump cycle, and time, in CSV format. These parameters encompass any data required for stress corrosion testing analysis, physics-informed machine learning models, or digital twins.

### 6. Remote monitoring capability

The parameters of the heater and pump should be adjustable remotely via the cloud. Firmware for both ESP32 and Arduino Uno R3 should support Over the Air (OTA) updates. Additionally, the Kill Command should also be executed via OTA.

## 2. System Requirements

This system is employed for conducting stress corrosion cracking experiments. It provides heating and a corrosive medium for the dog-bone samples during creep loading. The cartridge heater enables users to set the desired temperature, while the peristaltic pump propels MgCl2 (corrosive medium) through the copper pipes and cells, exposing the samples to the corrosive environment. The entire system should function in a quasi-automated mode.

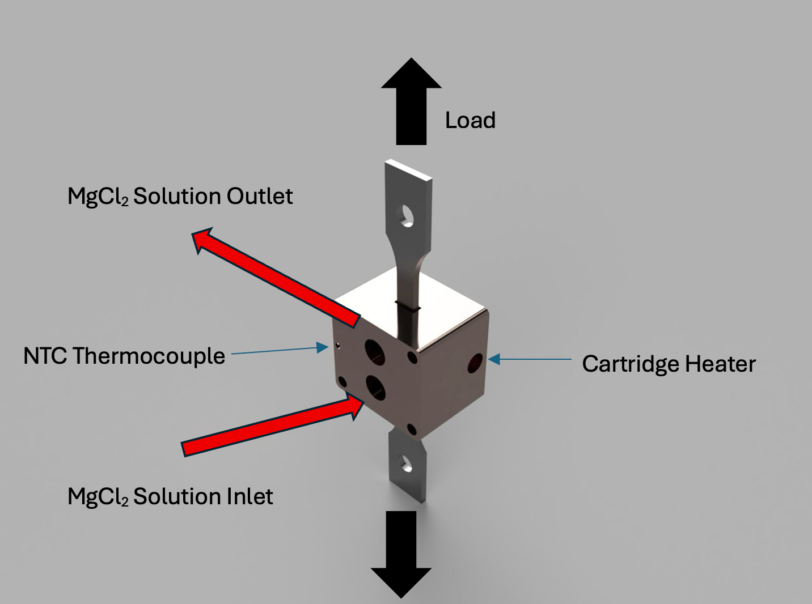
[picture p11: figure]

Fig 2. The hardware schematic of the system

## 2.1. Functional Requirements

ID | Requirement
FR-001 | Measure system temperature
FR-002 | Control heater output
FR-003 | Control pump circulations
FR-004 | Log data
FR-005 | Provide a method to monitor remotely
FR-006 | Execute safety shutdowns
Table 1. List of required functions for the system to perform

## 2.2. Performance Requirements

ID | Requirement | Target
PR-001 | Telemetry update rate | 1Hz
PR-002 | Data retention | ≥ 1 year
PR-003 | Uptime | >99%
PR-004 | Network Latency | <2 s
Table 2. List of performance targets the system needs to achieve

## 3. System Overview
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

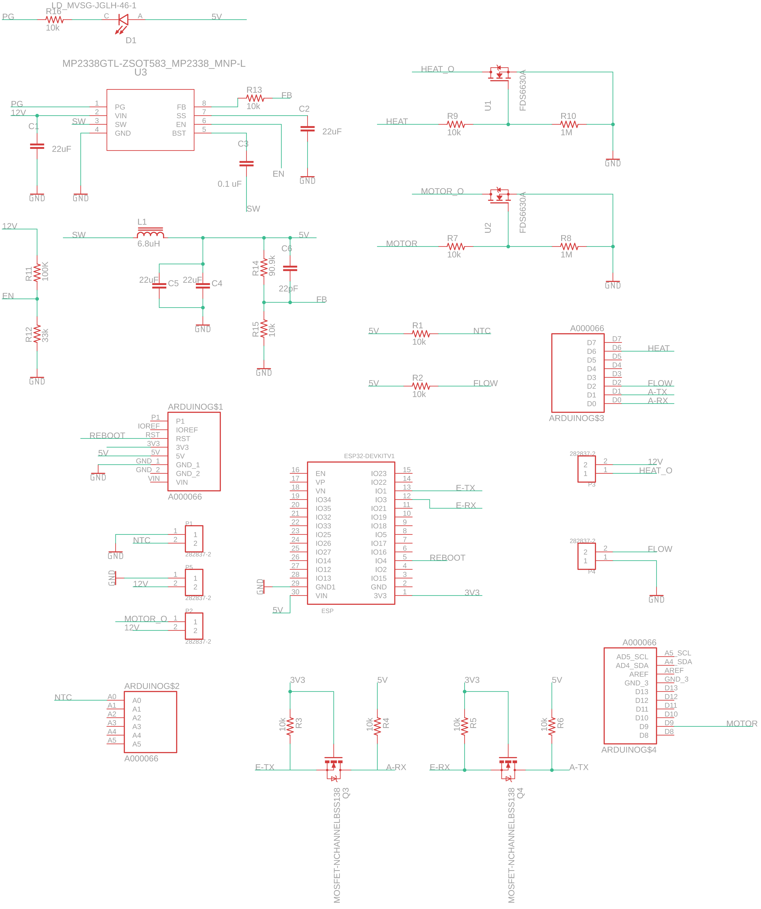
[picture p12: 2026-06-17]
docs/Design File/PCB V1/PCB Schematic.png

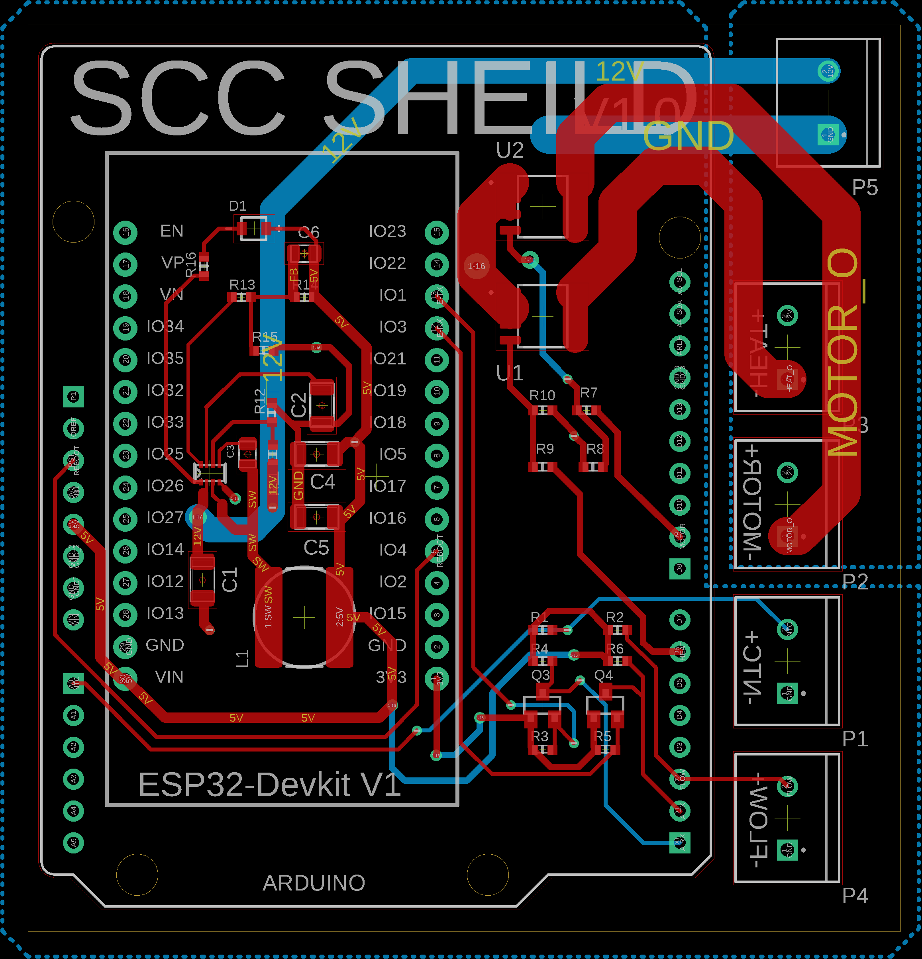
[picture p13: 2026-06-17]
docs/Design File/PCB V1/PCB Borad Layout.png

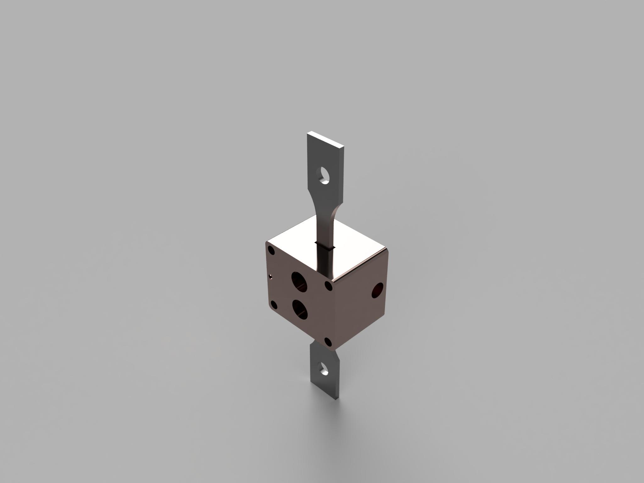
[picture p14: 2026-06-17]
docs/Photo:Render/SCC CAD Render.JPEG

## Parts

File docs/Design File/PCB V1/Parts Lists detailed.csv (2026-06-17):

Part | Value | Device | Package | Description | AVAILABILITY | CHECK_PRICES | COPYRIGHT | CREATED_BY | DATASHEET | DESCRIPTION | DIGIKEY_PART_NUMBER | MANUFACTURER | MANUFACTURER_NAME | MANUFACTURER_PART_NUMBER | MAXIMUM_PACKAGE_HEIGHT | MF | MP | MPN | PACKAGE | PARTREV | PRICE | PROD_ID | PURCHASE-URL | SNAPEDA_LINK | STANDARD
ARDUINO | A000066 | A000066 | ARDUINO_A000066 | Check availability | In Stock | https://www.snapeda.com/parts/A000066/Arduino/view-part/?ref=eda |  |  |  | Arduino UNO Rev3 Microcontroller Board, ATmega328P | Arduino A000066 |  |  |  |  |  | Arduino | A000066 |  | Non-Standard Arduino |  | None |  | https://www.snapeda.com/api/url_track_click_mouser/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 uno r3 | https://www.snapeda.com/parts/A000066/Arduino/view-part/?ref=snap
C1 | 22uF | GRM31CR60J107ME39L | CAP_1206 | CAP CER 100UF 6.3V X5R 1206 |  |  |  | PCBLayout.com |  |  | GRM31CR60J107ME39L | Murata Electronics North America |  |  |  |  |  | GRM31CR60J107ME39L | SMD 1206
C2 | 22uF | GRM31CR60J107ME39L | CAP_1206 | CAP CER 100UF 6.3V X5R 1206 |  |  |  | PCBLayout.com |  |  | GRM31CR60J107ME39L | Murata Electronics North America |  |  |  |  |  | GRM31CR60J107ME39L | SMD 1206
C3 | 0.1 uF | CC0805KRX7R9BB104 | CAP_0805 | CAP CER 0.1UF 50V X7R 0805 |  |  |  | PCBLayout.com |  |  | 311-1140-2-ND | Yageo |  |  |  |  |  | CC0805KRX7R9BB104 | SMD 0805
C4 | 22uF | GRM31CR60J107ME39L | CAP_1206 | CAP CER 100UF 6.3V X5R 1206 |  |  |  | PCBLayout.com |  |  | GRM31CR60J107ME39L | Murata Electronics North America |  |  |  |  |  | GRM31CR60J107ME39L | SMD 1206
C5 | 22uF | GRM31CR60J107ME39L | CAP_1206 | CAP CER 100UF 6.3V X5R 1206 |  |  |  | PCBLayout.com |  |  | GRM31CR60J107ME39L | Murata Electronics North America |  |  |  |  |  | GRM31CR60J107ME39L | SMD 1206
ESP | ESP32DEVKITV1 | ESP32DEVKITV1 | ESP32-DEVKITV1
L1 | 6.8uH | INDUCTOR-BOURNS_SRN8040 | INDUCTOR-BOURNS_SRN8040 | POWER INDUCTOR
P1 | 282837-2 | 282837-2 | TE_282837-2 |  | Good |  |  |  |  | TERMINAL BLOCK 3.5MM 2POS PCB |  |  |  |  |  | On Shore | OSTTE020104 |  | None | G3 | 0.28 USD
P2 | 282837-2 | 282837-2 | TE_282837-2 |  | Good |  |  |  |  | TERMINAL BLOCK 3.5MM 2POS PCB |  |  |  |  |  | On Shore | OSTTE020104 |  | None | G3 | 0.28 USD
P3 | 282837-2 | 282837-2 | TE_282837-2 |  | Good |  |  |  |  | TERMINAL BLOCK 3.5MM 2POS PCB |  |  |  |  |  | On Shore | OSTTE020104 |  | None | G3 | 0.28 USD
P4 | 282837-2 | 282837-2 | TE_282837-2 |  | Good |  |  |  |  | TERMINAL BLOCK 3.5MM 2POS PCB |  |  |  |  |  | On Shore | OSTTE020104 |  | None | G3 | 0.28 USD
P5 | 282837-2 | 282837-2 | TE_282837-2 |  | Good |  |  |  |  | TERMINAL BLOCK 3.5MM 2POS PCB |  |  |  |  |  | On Shore | OSTTE020104 |  | None | G3 | 0.28 USD
Q3 | MOSFET-NCHANNELBSS138 | MOSFET-NCHANNELBSS138 | SOT23 | Common NMOSFET Parts |  |  |  |  |  |  |  |  |  |  |  |  |  |  |  |  |  | TRANS-00830
Q4 | MOSFET-NCHANNELBSS138 | MOSFET-NCHANNELBSS138 | SOT23 | Common NMOSFET Parts |  |  |  |  |  |  |  |  |  |  |  |  |  |  |  |  |  | TRANS-00830
R1 | 10k | RC-MASTER-SMD_R_0603MP | RC-MASTER-SMD_R0603MP | RESISTOR
R2 | 10k | RC-MASTER-SMD_R_0603MP | RC-MASTER-SMD_R0603MP | RESISTOR
R3 | 10k | RC-MASTER-SMD_R_0603MP | RC-MASTER-SMD_R0603MP | RESISTOR
R4 | 10k | RC-MASTER-SMD_R_0603MP | RC-MASTER-SMD_R0603MP | RESISTOR
R5 | 10k | RC-MASTER-SMD_R_0603MP | RC-MASTER-SMD_R0603MP | RESISTOR
R6 | 10k | RC-MASTER-SMD_R_0603MP | RC-MASTER-SMD_R0603MP | RESISTOR
R7 | 10k | RC-MASTER-SMD_R_0603MP | RC-MASTER-SMD_R0603MP | RESISTOR
R8 | 1M | RC-MASTER-SMD_R_0603MP | RC-MASTER-SMD_R0603MP | RESISTOR
R9 | 10k | RC-MASTER-SMD_R_0603MP | RC-MASTER-SMD_R0603MP | RESISTOR
R10 | 1M | RC-MASTER-SMD_R_0603MP | RC-MASTER-SMD_R0603MP | RESISTOR
R11 | 100K | RC-MASTER-SMD_R_0603MP | RC-MASTER-SMD_R0603MP | RESISTOR
R12 | 33k | RC-MASTER-SMD_R_0603MP | RC-MASTER-SMD_R0603MP | RESISTOR
R13 | 10k | RC-MASTER-SMD_R_0603MP | RC-MASTER-SMD_R0603MP | RESISTOR
R14 | 90.9k | RC-MASTER-SMD_R_0603MP | RC-MASTER-SMD_R0603MP | RESISTOR
R15 | 10k | RC-MASTER-SMD_R_0603MP | RC-MASTER-SMD_R0603MP | RESISTOR
U1 | FDS6630A | FDS6630A | SOIC127P600X175-8N |  |  |  |  |  |  |  |  | ON SEMICONDUCTOR |  |  | 1.75 mm |  |  |  |  | C1 |  |  |  |  | IPC 7351B
U2 | FDS6630A | FDS6630A | SOIC127P600X175-8N |  |  |  |  |  |  |  |  | ON SEMICONDUCTOR |  |  | 1.75 mm |  |  |  |  | C1 |  |  |  |  | IPC 7351B
U3 | MP2338GTL-ZSOT583_MP2338_MNP-L | MP2338GTL-ZSOT583_MP2338_MNP-L | SOT583_MP2338_MNP-L |  |  |  | Copyright (C) 2026 Ultra Librarian. All rights reserved. |  | https://www.monolithicpower.com/en/documentview/productdocument/index/version/2/document_type/Datasheet/lang/en/sku/MP2338GTL | High-Efficiency 28V 3A 450kHz Synchronous Step-Down Converter In SOT583 Package |  |  | Monolithic Power Systems | MP2338GTL-Z

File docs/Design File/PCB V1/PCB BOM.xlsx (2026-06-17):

PCB BOM
Index | DigiKey Part # | Manufacturer Part Number | Manufacturer | Description | Customer Reference | Quantity | Backorder | Unit Price | Extended Price
1 | 13-TR0603KR-0710KLCT-ND | TR0603KR-0710KL | YAGEO | RES 10K OHM 0% 10% 1/10W 0603 |  | 25 | 0 | $0.07 | $1.63
2 | A113320-ND | 282837-2 | TE Connectivity AMP Connectors | TERM BLK 2P SIDE ENT 5.08MM PCB |  | 5 | 0 | $0.87 | $4.35
3 | S7013-ND | PPTC151LFBN-RC | Sullins Connector Solutions | CONN HDR 15POS 0.1 TIN PCB |  | 2 | 0 | $0.82 | $1.64
4 | 587-3246-1-ND | TMK316BBJ226ML-T | Taiyo Yuden | CAP CER 22UF 25V X5R 1206 |  | 20 | 0 | $0.09 | $1.80
5 | 490-10672-1-ND | GCM155R71H104KE02D | Murata Electronics | CAP CER 0.1UF 50V X7R 0402 |  | 10 | 0 | $0.03 | $0.32
6 | 1276-2605-1-ND | CL21C220JB61PNC | Samsung Electro-Mechanics | CAP CER 22PF 50V C0G/NP0 0805 |  | 10 | 0 | $0.08 | $0.78
7 | 475-LDMVSG-JGLH-46-1CT-ND | LD MVSG-JGLH-46-1-20-R18-Z | ams-OSRAM USA INC. | LED MINI TOPLED BLUE 459NM SMD |  | 2 | 0 | $0.57 | $1.14
8 | SRN8040-6R8YCT-ND | SRN8040-6R8Y | Bourns Inc. | FIXED IND 6.8UH 3.9A 33 MOHM SMD |  | 2 | 0 | $0.53 | $1.06
9 | 118-CMP0603-FX-1004ELFCT-ND | CMP0603-FX-1004ELF | Bourns Inc. | RESHIGHPOWER 0603 1M 1% 1/4W TC1 |  | 4 | 0 | $0.16 | $0.64
10 | 118-CMP0805-FX-1003ELFCT-ND | CMP0805-FX-1003ELF | Bourns Inc. | RESHIGHPOWER 0805 100K 1% 1/2W T |  | 4 | 0 | $0.18 | $0.72
11 | RMCF0603FT1K00CT-ND | RMCF0603FT1K00 | Stackpole Electronics Inc | RES 1K OHM 1% 1/10W 0603 |  | 10 | 0 | $0.01 | $0.06
12 | CR0603-FX-9092ELFCT-ND | CR0603-FX-9092ELF | Bourns Inc. | RES SMD 90.9K OHM 1% 1/10W 0603 |  | 10 | 0 | $0.02 | $0.20
13 | FDS8896CT-ND | FDS8896 | onsemi | MOSFET N-CH 30V 15A 8SOIC |  | 4 | 0 | $1.19 | $4.76
14 | BSS138CT-ND | BSS138 | onsemi | MOSFET N-CH 50V 220MA SOT23-3 |  | 10 | 0 | $0.17 | $1.70
15 | 1589-MP2338GTL-ZCT-ND | MP2338GTL-Z | Monolithic Power Systems Inc. | IC REG BUCK ADJ 3A SOT583 |  | 2 | 0 | $1.55 | $3.10
16 | WM50014-36-ND | 22284360 | Molex | CONN HEADER VERT 36POS 2.54MM |  | 4 | 0 | $1.12 | $4.48
 |  |  |  |  |  |  |  | Sub Total | $28.38

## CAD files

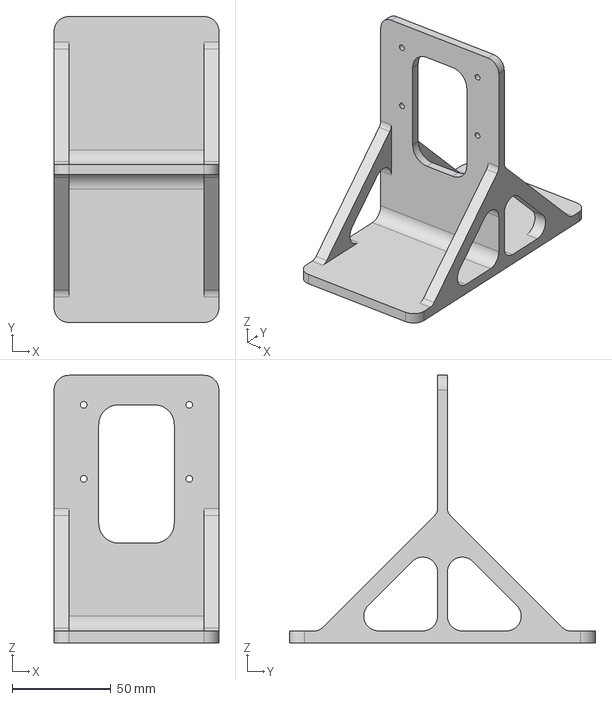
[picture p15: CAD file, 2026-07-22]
docs/Design File/CAD Step File/motor stand v3.step
83.5 x 155.0 x 135.5 mm

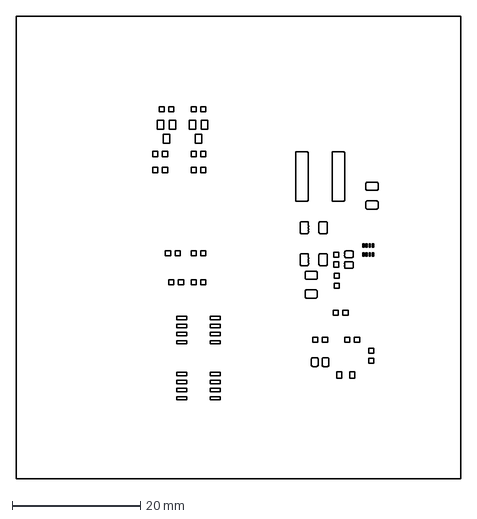
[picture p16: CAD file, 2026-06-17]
docs/Design File/CAD Step File/PCB Stencil/SCC.dxf
69.5 x 72.2 mm

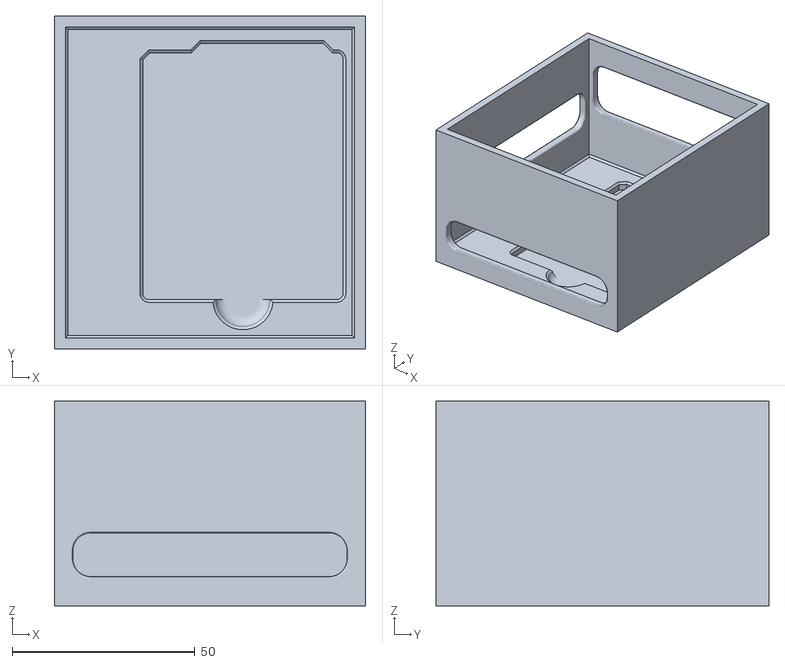
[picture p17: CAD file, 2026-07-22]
docs/Design File/Stl 3d Printing File/Electronic Box v7.stl
85.0 x 91.0 x 56.0

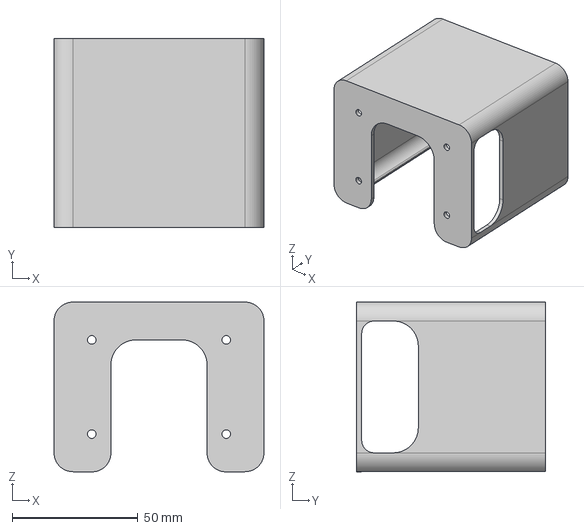
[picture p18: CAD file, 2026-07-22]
docs/Design File/CAD Step File/motor cover v1.step
83.5 x 75.0 x 67.5 mm

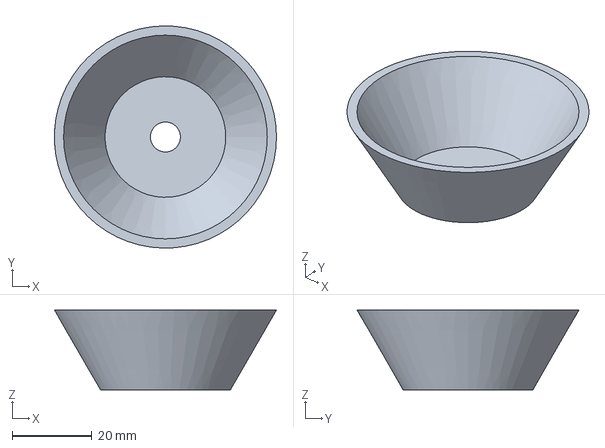
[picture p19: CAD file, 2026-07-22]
docs/Design File/CAD Step File/Fiz Container.step
55.6 x 55.6 x 20.0 mm

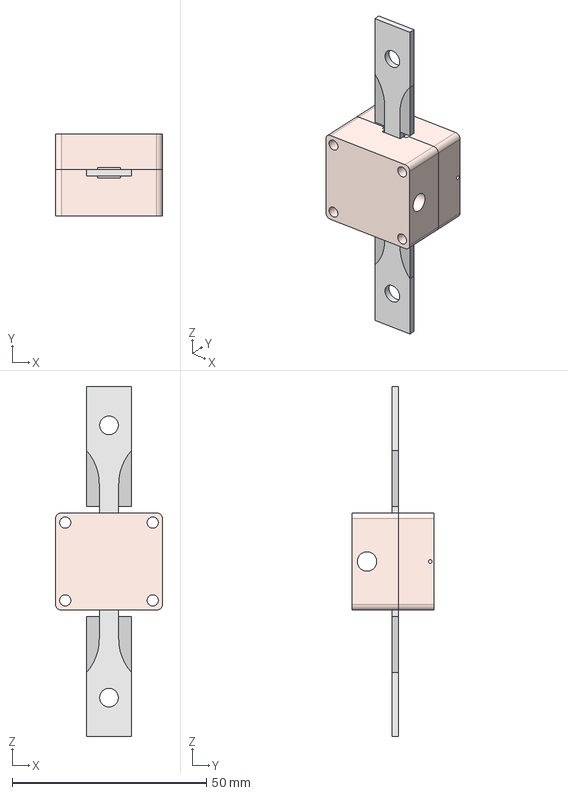
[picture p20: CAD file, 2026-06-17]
docs/Design File/CAD Step File/Corrosion Cell CAD.step
27.5 x 21.1 x 90.0 mm
Sample Long gage sec
M1
M2

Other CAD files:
docs/Design File/Dwg Laser Cutting File/316 Updated Drawing v1.dwg
docs/Design File/Stl 3d Printing File/Fiz Container.stl
docs/Design File/Stl 3d Printing File/motor cover v1.stl
docs/Design File/Stl 3d Printing File/motor stand v3.stl

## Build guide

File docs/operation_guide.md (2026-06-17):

# 11. Operation Guide

## 11.1. Startup Checks

Before starting a test run, verify that the heater, pump, thermistor, Arduino controller, Intel NUC USB gateway, backend, database, and HMI dashboard are powered and communicating. Confirm that the latest telemetry updates in the dashboard, no critical alarm is active, and the manual kill state is clear.

## 11.2. Normal Operation

**Operator responsibilities:**

- Confirm that the SCC rig is physically safe to operate before enabling heat or pump activity.
- Keep the Operations dashboard open during testing and verify that telemetry is updating approximately every few seconds.
- Monitor current temperature, setpoint, temperature error, heater PWM, pump status, and controller mode.
- Verify that the bath remains within the intended operating window and that heater lockout, manual kill, and hard kill indicators remain clear.
- Confirm that pump cycles occur only when the controller reports sufficient thermal headroom.
- Review active alarms and event timeline entries during each operating session.
- Do not treat ML predictions or MPC recommendations as safety controls; they are advisory only.
- Record abnormal behavior, operator actions, alarms, and shutdown events in the test log.
- Stop the test using the manual emergency control or physical disconnect if unsafe conditions are observed.

**Alarm response procedures:**

| Alarm | Severity | Operator response |
| --- | --- | --- |
| `HARD_KILL` | Critical | Treat as an emergency shutdown. Verify heater PWM is `0`, pump/motor output is off, allow the bath to cool, inspect hardware, and do not restart until the cause is identified. |
| `MANUAL_KILL` | Critical | Confirm the manual shutdown was intentional. Keep outputs disabled until the rig is inspected and the operator is ready to clear the manual kill state. |
| `SENSOR_FAULT` | Critical | Stop operation, inspect thermistor wiring and ADC input, verify readings with an independent thermometer if available, and restart only after valid telemetry is restored. |
| `HIGH_TEMP_CRITICAL` | Critical | Stop heating immediately, verify heater output is de-energized, allow cooling, and inspect for heater control or sensor failure. |
| `HEATER_LOCKOUT` | Warning | Continue monitoring while the heater remains disabled. Do not clear or restart until temperature falls below the lockout reset threshold and no other fault is active. |
| `HIGH_TEMP_WARNING` | Warning | Watch temperature trend and heater PWM closely. Prepare to stop the test if temperature continues rising. |
| `SLOW_RECOVERY` | Warning | Inspect pump operation, flow path, bath mixing, and temperature recovery behavior after pump cycles. |
| `EXCESSIVE_PUMP_COOLING` | Warning | Check pump dose duration, flow rate, solution temperature, and thermal compensation settings. |

If any critical alarm occurs, the operator must prioritize physical safety over data collection. The test should remain stopped until the root cause is reviewed.

**Monitoring requirements:**

- Temperature, setpoint, and temperature error shall be monitored continuously during active heating.
- Heater PWM shall be checked to confirm that heating output responds normally and drops to `0` during lockout, manual kill, hard kill, or sensor fault states.
- Pump status, motor PWM, pump recovery time, and last pump temperature drop shall be monitored to identify blocked flow, excessive cooling, or failed recovery.
- Alarm status shall be reviewed through the active alarm panel during operation.
- Event timeline entries for pump start, pump end, pump recovery, hard kill, and sensor fault events shall be reviewed after each test run.
- NUC gateway and backend connectivity shall be checked if dashboard values stop updating.
- PostgreSQL data logging shall be verified by confirming that recent telemetry appears in the history and latest telemetry endpoints.
- Operators shall remain near the rig during active heating unless an independent physical safety cutoff and approved unattended-operation procedure are in place.
- Any abnormal noise, smell, overheating, fluid leak, unexpected pump behavior, or stale telemetry shall trigger test pause or shutdown.

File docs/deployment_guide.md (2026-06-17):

# 10. Deployment Guide

## 10.1. Server Requirements

**Operating System:** Linux, macOS, or Windows with Docker Desktop. A Linux host is preferred for continuous operation.

**CPU:** Minimum 2 CPU cores. Four cores are recommended if running the backend, database, MQTT broker, and dashboard on the same machine.

**RAM:** Minimum 4 GB. Eight GB is recommended for stable Docker operation, database caching, and frontend development services.

**Storage:** Minimum 10 GB free disk space. Twenty GB or more is recommended to allow PostgreSQL data growth, Docker images, firmware artifacts, logs, and model files.

**Network:** The Intel NUC gateway must be able to reach the backend API. Required local ports are `5050` for the backend API, `5173` for the dashboard, and `5432` for PostgreSQL if direct database access is needed. Port `1883` is only required when using the legacy ESP32 MQTT relay.

**Software:** Docker Engine or Docker Desktop with Docker Compose support. For non-Docker development, Python `3.11`, Node.js `22`, PostgreSQL, Mosquitto, and the backend Python dependencies are required.

## 10.2. Docker Services

| Service | Image or build source | Port | Purpose |
| --- | --- | --- | --- |
| Backend | `backend/Dockerfile` using Python `3.11-slim` | `5050:5000` | Runs the Flask/Gunicorn API, MQTT subscriber, telemetry parser, alarm rules, ML prediction, MPC advisory logic, and firmware command APIs |
| Frontend | `node:22-alpine` | `5173:5173` | Runs the React/Vite HMI dashboard for live monitoring, alarms, trends, MPC, ML, equipment health, settings, and firmware views |
| PostgreSQL | `postgres:16` | `5432:5432` | Stores telemetry, alarms, events, pump-cycle records, predictions, command state, and other backend data |
| MQTT Broker | `eclipse-mosquitto:2` | `1883:1883`, `9001:9001` | Receives legacy ESP32 telemetry messages and exposes MQTT/WebSocket transport for local communication |
| Cloudflare Tunnel | `cloudflare/cloudflared:latest` | outbound tunnel | Optional public access layer for the backend and dashboard when `CLOUDFLARE_TUNNEL_TOKEN` is configured |

## 10.3. Deployment Procedure

1. Clone or copy the repository to the deployment server.

   ```bash
   git clone <repository-url>
   cd scc-control-platform
   ```

2. Create the environment file from the example.

   ```bash
   cp .env.example .env
   ```

3. Configure required environment variables in `.env`.

   ```text
   API_WRITE_KEY=<shared-write-key-for-backend-and-dashboard>
   CORS_ORIGINS=http://localhost:5173
   PUBLIC_BASE_URL=http://localhost:5050
   MQTT_HOST=mosquitto
   MQTT_PORT=1883
   MQTT_BASE_TOPIC=scc
   ```

   If email alerts are required, also configure `ALERT_EMAIL_ENABLED`, `ALERT_EMAIL_TO`, `ALERT_EMAIL_FROM`, `SMTP_HOST`, `SMTP_PORT`, `SMTP_USERNAME`, `SMTP_PASSWORD`, and `SMTP_STARTTLS`.

4. Start the Docker services.

   ```bash
   docker compose up --build
   ```

5. Verify that the containers are running.

   ```bash
   docker compose ps
   ```

6. Open the application endpoints.

   ```text
   Backend API: http://localhost:5050
   Frontend HMI: http://localhost:5173
   PostgreSQL: localhost:5432
   MQTT broker: localhost:1883
   ```

7. Start the Intel NUC USB gateway on the host connected to the Arduino.

   ```bash
   cd backend
   python -m app.services.nuc_gateway --serial-port /dev/ttyACM0 --api-base-url http://localhost:5050
   ```

8. Verify connectivity by confirming that telemetry reaches the backend and appears in the dashboard.

   ```text
   GET http://localhost:5050/api/latest
   ```

9. Run validation checks before operating the SCC rig.

   ```bash
   pytest backend/tests
   pio test -d firmware/arduino/SCC-V1.4 -e native
   ```

10. For production or remote access, configure the Cloudflare tunnel token in `.env` and confirm the public URLs route to the backend and frontend services.

    ```text
    CLOUDFLARE_TUNNEL_TOKEN=<cloudflare-token>
    ```

## 10.4. Post-Deployment Checks

| Check | Expected Result |
| --- | --- |
| Backend health/API access | Backend responds on `http://localhost:5050` |
| Dashboard access | HMI loads on `http://localhost:5173` |
| Database startup | PostgreSQL container reports healthy |
| NUC gateway connectivity | Gateway logs show Arduino serial reads and successful backend telemetry posts |
| MQTT broker availability | Required only for legacy ESP32 relay deployments |
| Latest telemetry | `/api/latest` returns the most recent telemetry row after gateway publishing begins |
| Alarm display | Active safety alarms appear in backend API responses and the dashboard |
| Manual kill command | `KILL 1` command can be queued only when write authentication is configured |
| Data persistence | PostgreSQL volume `postgres-data` persists after container restart |

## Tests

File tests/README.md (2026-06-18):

# Test Sections

- [Telemetry Pipeline](telemetry-pipeline/README.md): Arduino mock CSV package -> Intel NUC gateway -> Flask -> PostgreSQL verification.
- [Heater Testing](heater-testing/README.md): standalone Arduino heater hold test controlled by `G` and `S` serial commands.
- [NTC Testing](ntc-testing/README.md): standalone Arduino live NTC temperature readout.
- [Motor Testing](motor-testing/README.md): standalone Arduino motor test controlled by `G` and `S` serial commands.

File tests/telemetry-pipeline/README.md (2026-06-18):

# Telemetry Pipeline Test Section

This section is isolated from `firmware/`. It is for testing the live NUC path only:

```text
Arduino mock telemetry source -> Intel NUC gateway -> Flask /api/telemetry -> PostgreSQL
```

It does not start or call the HMI, ML prediction, or MPC endpoints. The verifier reads PostgreSQL directly and compares the final stored telemetry rows with the original Arduino CSV fixture.

## Test Project

- `Firmwares/Arduino Software Testing`: Arduino Uno project that emits one repeatable mock telemetry package over USB serial.

The mock package contains:

```text
MOCK_TELEMETRY_PACKAGE_BEGIN <n>
event,ms,temp_c,...
<fixture row 1>
<fixture row 2>
<fixture row 3>
MOCK_TELEMETRY_PACKAGE_END <n>
```

The NUC gateway ignores the package marker and header lines, parses the three CSV rows, and posts JSON telemetry to Flask.

Board choice:

- Arduino: `uno`

## Hardware Wiring

Connect the Arduino Uno directly to the Intel NUC over USB. No ESP32, UART jumper wiring, or Wi-Fi test firmware is used for this pipeline test.

## Backend and NUC Gateway Setup

Start the backend and make sure PostgreSQL is available. If write authentication is enabled, set the same `API_WRITE_KEY` for the backend and the NUC gateway.

In a terminal on the NUC, run the gateway against the Arduino USB port:

```bash
cd backend
python -m app.services.nuc_gateway \
  --serial-port /dev/ttyACM0 \
  --api-base-url http://localhost:5050
```

Use `/dev/ttyUSB0` or the macOS `/dev/cu.usbmodem*` path if that is where the Arduino appears. Use `http://localhost:5000` when running Flask directly instead of through Docker port mapping.

## Build and Upload the Arduino Mock Source

From `scc-control-platform`:

```bash
pio run -d "tests/telemetry-pipeline/Firmwares/Arduino Software Testing" -t upload
```

Once the Arduino resets, it repeatedly sends the mock telemetry package over USB. The NUC gateway should log parsed telemetry posts.

## Verify PostgreSQL Rows Match Arduino CSV

After the NUC gateway posts at least one mock package, run:

```bash
python3 tests/telemetry-pipeline/scripts/verify_telemetry_pipeline.py \
  --source tests/telemetry-pipeline/fixtures/arduino_telemetry_sample.csv \
  --database-url "$DATABASE_URL" \
  --mode verify-db
```

For a backend-only smoke test without Arduino hardware, the same verifier can post the sample rows directly to Flask and then compare PostgreSQL:

```bash
python3 tests/telemetry-pipeline/scripts/verify_telemetry_pipeline.py \
  --source tests/telemetry-pipeline/fixtures/arduino_telemetry_sample.csv \
  --database-url "$DATABASE_URL" \
  --api-url http://localhost:5050/api/telemetry \
  --api-key "$API_WRITE_KEY" \
  --mode post-and-verify
```

`post-and-verify` checks that `ml_predictions` and `mpc_recommendations` counts do not change. It only calls `/api/telemetry`.

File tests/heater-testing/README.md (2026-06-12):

# Heater Testing

Standalone Arduino heater test project. This does not use or modify anything inside `firmware/`.

The sketch uses the same Arduino hardware assumptions as `firmware/arduino/SCC-V1.4`:

- Thermistor input: `A0`
- Heater PWM pin: `6`
- ADC-to-temperature fit: `tempC = -0.1871 * adc + 167.97`
- Heater PWM limit: `200`
- Hard safety cutoff: `130.00 C`

## Serial Commands

Open Serial Monitor at `115200`.

- `G`: start heater control and hold `120.00 C`
- `S`: stop heater immediately

The sketch prints CSV status lines:

```text
state,ms,temp_c,adc,setpoint_c,pwm,enabled,hard_kill
```

## Build And Upload

From `scc-control-platform`:

```bash
pio run -d "tests/heater-testing/Firmwares/Arduino Heater Testing" -t upload
pio device monitor -d "tests/heater-testing/Firmwares/Arduino Heater Testing" -b 115200
```

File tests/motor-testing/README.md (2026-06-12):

# Motor Testing

Standalone Arduino motor test project. This does not use or modify anything inside `firmware/`.

The sketch uses the same motor output as `firmware/arduino/SCC-V1.4`:

- Motor PWM pin: `9`
- Motor run PWM: `155`

## Serial Commands

Open Serial Monitor at `115200`.

- `G`: turn motor on at PWM `155`
- `S`: turn motor off

The sketch prints CSV status lines:

```text
state,ms,pwm,enabled
```

## Build And Upload

From `scc-control-platform`:

```bash
pio run -d "tests/motor-testing/Firmwares/Arduino Motor Testing" -t upload
pio device monitor -d "tests/motor-testing/Firmwares/Arduino Motor Testing" -b 115200
```

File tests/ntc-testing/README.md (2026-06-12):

# NTC Testing

Standalone Arduino NTC temperature readout project. This does not use or modify anything inside `firmware/`.

The sketch uses the same temperature input and conversion as `firmware/arduino/SCC-V1.4`:

- Thermistor input: `A0`
- ADC-to-temperature fit: `tempC = -0.1871 * adc + 167.97`
- Clamp range: `-20.00 C` to `220.00 C`

Open Serial Monitor at `115200`. The sketch prints live CSV readings once per second:

```text
ms,adc,temp_c
```

## Build And Upload

From `scc-control-platform`:

```bash
pio run -d "tests/ntc-testing/Firmwares/Arduino NTC Testing" -t upload
pio device monitor -d "tests/ntc-testing/Firmwares/Arduino NTC Testing" -b 115200
```

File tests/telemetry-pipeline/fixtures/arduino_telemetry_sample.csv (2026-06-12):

event | ms | temp_c | adc | dtemp_c_per_s | setpoint_c | mode | heater_pwm | heating | heater_lockout | pump_enabled | pump_allowed | pump_on | motor_pwm | motor_on_ms | motor_period_ms | temp_before_pump_c | min_temp_after_pump_c | last_pump_drop_c | recovery_time_s | manual_kill | hard_kill | uptime_s
0 | 123456 | 126.42 | 222 | -0.1300 | 125.00 | 3 | 184 | 1 | 0 | 1 | 1 | 0 | 155 | 150 | 30000 | 127.20 | 124.80 | 2.40 | 18.50 | 0 | 0 | 300
1 | 124456 | 126.70 | 223 | 0.2800 | 125.00 | 3 | 190 | 1 | 0 | 1 | 1 | 1 | 180 | 150 | 30000 | 126.70 | 126.70 | 0.00 | 0.00 | 0 | 0 | 301
2 | 125456 | 124.90 | 220 | -1.8000 | 125.00 | 3 | 210 | 1 | 0 | 1 | 1 | 0 | 0 | 150 | 30000 | 126.70 | 124.90 | 1.80 | 0.00 | 0 | 0 | 302

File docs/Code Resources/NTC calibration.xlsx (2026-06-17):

ADC | Deg F | Deg C
507 | 162 | 72.22222222
492 | 167 | 75
486 | 165 | 73.88888889
437 | 195 | 90.55555556
398 | 202 | 94.44444444
353 | 219 | 103.8888889
298 | 236 | 113.3333333
276 | 238 | 114.4444444
250 | 247 | 119.4444444

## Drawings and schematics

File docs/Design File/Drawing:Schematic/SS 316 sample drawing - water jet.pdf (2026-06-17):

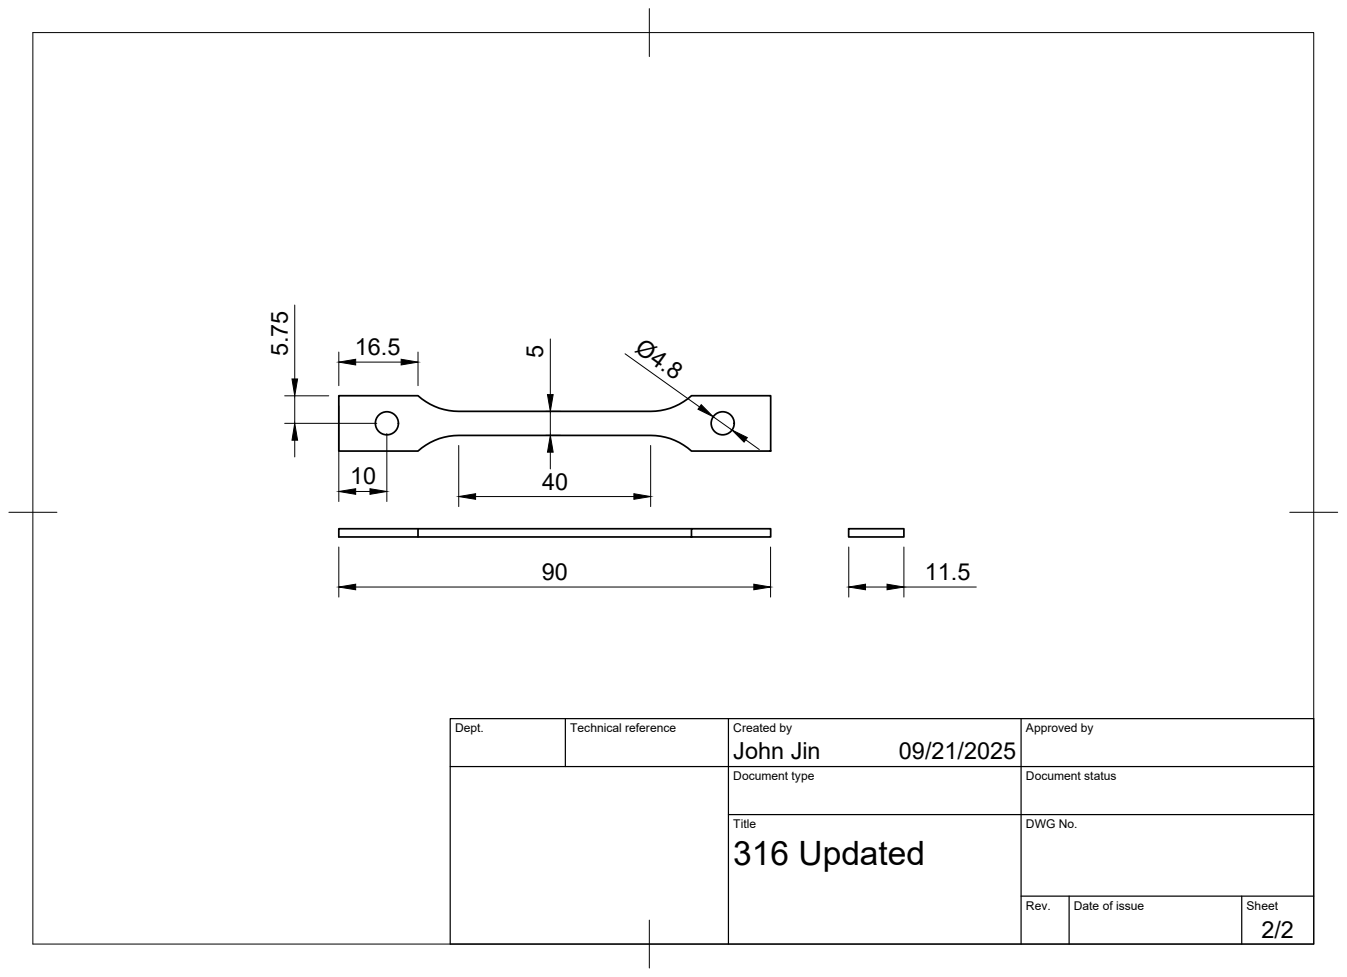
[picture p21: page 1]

Dept. | Technical reference | Created by John Jin 09/21/2025 | Approved by

Document type | Document status

Title 316 Updated | DWG No.

Rev. | Date of issue | Sheet 2/2

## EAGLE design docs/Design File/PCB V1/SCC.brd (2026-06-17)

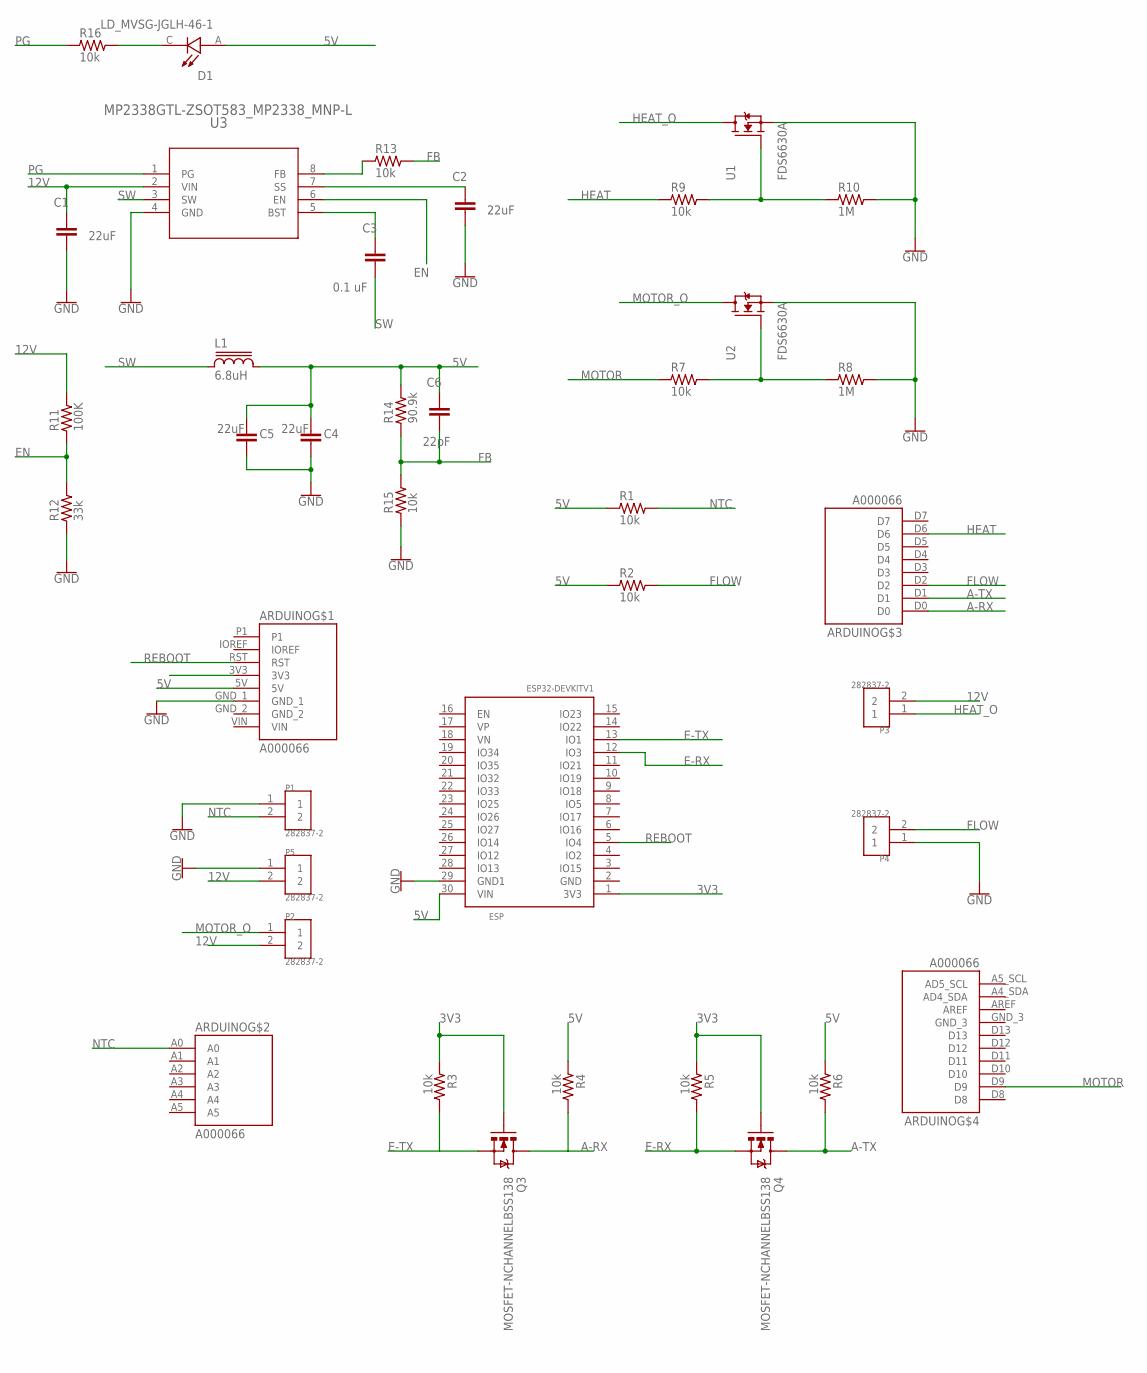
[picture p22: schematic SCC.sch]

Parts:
ARDUINO: A000066; ARDUINO_A000066
C1, C2, C4, C5: 22uF; CAP_1206
C3: 0.1 uF; CAP_0805
C6: 22pF; CAP_0805
D1: LD_MVSG-JGLH-46-1; LED_LD_MVSG-JGLH-46-1
ESP: ESP32DEVKITV1; ESP32-DEVKITV1
L1: 6.8uH; INDUCTOR-BOURNS_SRN8040
P1, P2, P3, P4, P5: 282837-2; TE_282837-2
Q3, Q4: MOSFET-NCHANNELBSS138; SOT23
R1, R2, R3, R4, R5, R6, R7, R9, R13, R15, R16: 10k; RC-MASTER-SMD_R0603MP
R8, R10: 1M; RC-MASTER-SMD_R0603MP
R11: 100K; RC-MASTER-SMD_R0603MP
R12: 33k; RC-MASTER-SMD_R0603MP
R14: 90.9k; RC-MASTER-SMD_R0603MP
U1, U2: FDS6630A; SOIC127P600X175-8N
U3: MP2338GTL-ZSOT583_MP2338_MNP-L; SOT583_MP2338_MNP-L

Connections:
3V3: ESP.1 (3V3), Q3.1 (G), Q4.1 (G), R3.1, R5.1
5V: ARDUINO.5V, C4.1, C5.1, C6.1, D1.A, ESP.30 (VIN), L1.2, R1.1, R2.1, R4.1, R6.1, R14.2
12V: C1.1, P2.2, P3.2, P5.2, R11.2, U3.2 (VIN)
A-RX: ARDUINO.D0, Q3.3 (D), R4.2
A-TX: ARDUINO.D1, Q4.3 (D), R6.2
E-RX: ESP.12 (IO3), Q4.2 (S), R5.2
E-TX: ESP.13 (IO1), Q3.2 (S), R3.2
EN: R11.1, R12.2, U3.6 (EN)
FB: C6.2, R13.2, R14.1, R15.2
FLOW: ARDUINO.D2, P4.2, R2.2
GND: ARDUINO.GND_1, C1.2, C2.2, C4.2, C5.2, ESP.29 (GND1), P1.1, P4.1, P5.1, R8.2, R10.2, R12.1, R15.1, U1.1 (S), U1.2 (S), U1.3 (S), U2.1 (S), U2.2 (S), U2.3 (S), U3.4 (GND)
GND_2: ARDUINO.GND_2
GND_3: ARDUINO.GND_3
HEAT: ARDUINO.D6, R9.1
HEAT_O: P3.1, U1.5 (D), U1.6 (D), U1.7 (D), U1.8 (D)
MOTOR: ARDUINO.D9, R7.1
MOTOR_O: P2.1, U2.5 (D), U2.6 (D), U2.7 (D), U2.8 (D)
unnamed: R7.2, R8.1, U2.4 (G)
unnamed: R9.2, R10.1, U1.4 (G)
unnamed: C3.1, U3.5 (BST)
unnamed: C2.1, U3.7 (SS)
unnamed: D1.C, R16.2
unnamed: R13.1, U3.8 (FB)
NTC: ARDUINO.A0, P1.2, R1.2
PG: R16.1, U3.1 (PG)
REBOOT: ARDUINO.RST, ESP.5 (IO4)
SW: C3.2, L1.1, U3.3 (SW)
VIN: ARDUINO.VIN

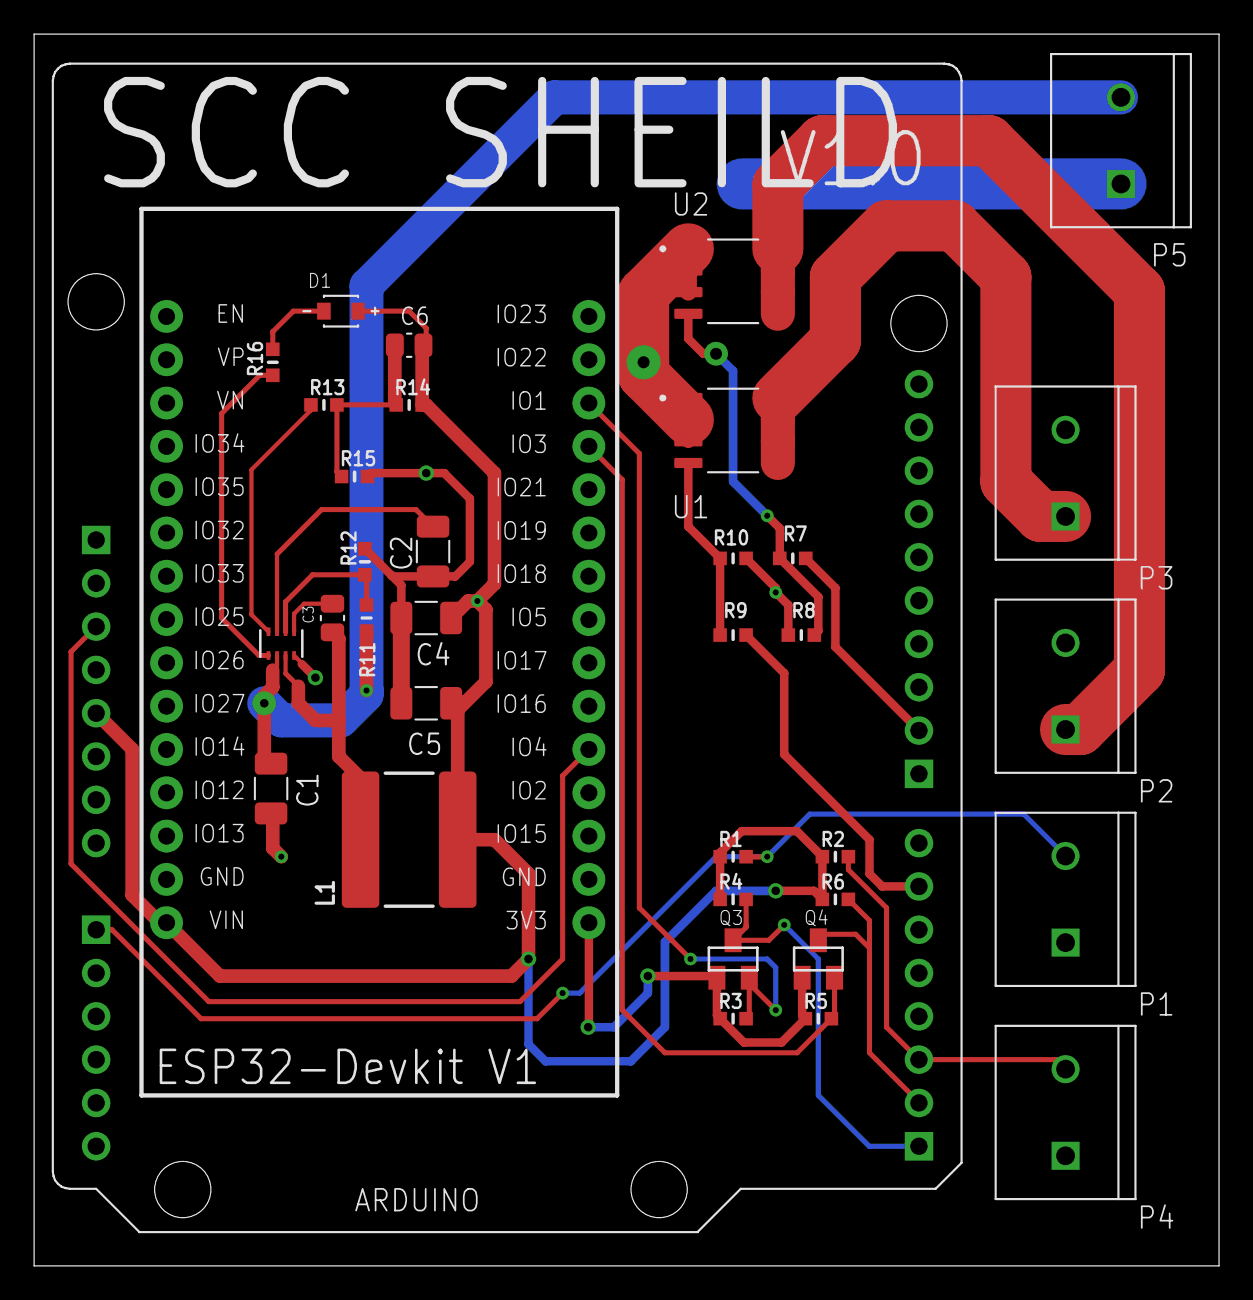
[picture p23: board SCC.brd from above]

Board: 2 copper layers, 69.5 x 72.2 mm, 36 parts (0 on the bottom side), 25 nets.

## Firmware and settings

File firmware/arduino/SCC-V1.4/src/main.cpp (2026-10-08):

#include <Arduino.h>
#include "actuators.h"
#include "bootloader_entry.h"
#include "config.h"
#include "controller.h"
#include "pump_policy.h"
#include "telemetry_schema.h"
#include "temperature.h"

#if ENABLE_SOFTWARE_BOOTLOADER_ENTRY && defined(__AVR__)
#include <avr/wdt.h>
#endif

static uint32_t lastControlMs = 0;
static uint32_t programStartMs = 0;
static bool runtimeExpired = false;
static bool pumpTempAllowed = false;
static bool hardKillActive = false;
static bool sensorFaultActive = false;
static bool manualKillActive = false;
static char serialCommandBuf[32];
static uint8_t serialCommandIdx = 0;

static bool pumpOnCmd = false;
static bool pumpWasOn = false;
static bool postPumpTracking = false;
static bool recoveryComplete = false;
static uint8_t pumpCmdPwm = 0;
static uint32_t lastPumpStartMs = 0;
static uint32_t lastPumpEndMs = 0;
static uint32_t recoveryTimeMs = 0;
static int16_t tempBeforeLastPumpCx100 = -32768;
static int16_t minTempAfterLastPumpCx100 = -32768;
static float tempRateCPerSec = 0.0f;
static uint32_t lastRateMs = 0;
static int16_t lastRateTempCx100 = 0;

#if ENABLE_SOFTWARE_BOOTLOADER_ENTRY
static bool bootloaderEntryPending = false;
#endif

enum CsvEvent : uint8_t {
  CSV_SAMPLE = 0,
  CSV_PUMP_START = 1,
  CSV_PUMP_END = 2,
  CSV_PUMP_RECOVERED = 3,
  CSV_HARD_KILL = 4,
  CSV_SENSOR_FAULT = 5
};

static void printCx100(int16_t valueCx100) {
  Serial.print(valueCx100 * 0.01f, 2);
}

static void printCx100OrBlank(int16_t valueCx100) {
  if (valueCx100 == -32768) {
    Serial.print(F("nan"));
    return;
  }
  printCx100(valueCx100);
}

static uint8_t controlModeCode() {
  return telemetryControlModeCode();
}

static uint8_t computePumpPwm(uint32_t now) {
  return pumpPwmForPhase(now - motorCycleStart);
}

static void printCsvHeader() {
  Serial.println(F(TELEMETRY_CSV_HEADER));
}

static void printCsvRow(uint8_t eventCode, uint32_t now, uint16_t adc, int16_t tempCx100) {
  int16_t dropCx100 = -32768;
  if (tempBeforeLastPumpCx100 != -32768 && minTempAfterLastPumpCx100 != -32768) {
    dropCx100 = tempBeforeLastPumpCx100 - minTempAfterLastPumpCx100;
  }

  Serial.print(eventCode);
  Serial.print(',');
  Serial.print(now);
  Serial.print(',');
  printCx100(tempCx100);
  Serial.print(',');
  Serial.print(adc);
  Serial.print(',');
  Serial.print(tempRateCPerSec, 4);
  Serial.print(',');
  printCx100(activeSetpointCx100);
  Serial.print(',');
  Serial.print(controlModeCode());
  Serial.print(',');
  Serial.print(lastPwm);
  Serial.print(',');
  Serial.print(heating ? 1 : 0);
  Serial.print(',');
  Serial.print(heaterLockout ? 1 : 0);
  Serial.print(',');
  Serial.print(motorEnabled ? 1 : 0);
  Serial.print(',');
  Serial.print(pumpTempAllowed ? 1 : 0);
  Serial.print(',');
  Serial.print(pumpOnCmd ? 1 : 0);
  Serial.print(',');
  Serial.print(pumpCmdPwm);
  Serial.print(',');
  Serial.print(MOTOR_ON_MS);
  Serial.print(',');
  Serial.print(MOTOR_PERIOD_MS);
  Serial.print(',');
  printCx100OrBlank(tempBeforeLastPumpCx100);
  Serial.print(',');
  printCx100OrBlank(minTempAfterLastPumpCx100);
  Serial.print(',');
  printCx100OrBlank(dropCx100);
  Serial.print(',');
  if (recoveryComplete) {
    Serial.print(recoveryTimeMs / 1000.0f, 2);
  } else {
    Serial.print(F("nan"));
  }
  Serial.print(',');
  Serial.print(manualKillActive ? 1 : 0);
  Serial.print(',');
  Serial.print(hardKillActive ? 1 : 0);
  Serial.print(',');
  Serial.println((now - programStartMs) / 1000);
}

static void stopHeater() {
  heaterSet(0);
  heaterEnabled = false;
  heating = false;
  heaterLockout = true;
  pidIntegral = 0.0f;
}

static void stopPump() {
  motorSet(false);
  motorEnabled = false;
  pumpTempAllowed = false;
  pumpOnCmd = false;
  pumpCmdPwm = 0;
}

static void forceSystemOff() {
  // This is the single fail-safe shutdown path used by boot, the web OFF
  // command, emergency stop, faults, and runtime expiry.
  stopHeater();
  stopPump();
}

static bool systemCanStart() {
  return !manualKillActive && !runtimeExpired && !sensorFaultActive;
}

static void startHeater(uint32_t now) {
  if (!heaterEnabled) {
    resetAutotune(now);
    heaterEnabled = true;
  }
}

static void startPump(uint32_t now) {
  if (motorEnabled) return;
  motorCycleStart = now;
  pumpTempAllowed = false;
  pumpOnCmd = false;
  pumpCmdPwm = 0;
  motorEnabled = true;
}

static void startSystem(uint32_t now) {
  // Every deliberate full-system start enables both independently controlled
  // actuators while preserving all controller safety gates.
  startHeater(now);
  startPump(now);
}

#if ENABLE_SOFTWARE_BOOTLOADER_ENTRY
static void resetForBootloaderEntry() {
#if defined(__AVR__)
  wdt_enable(WDTO_15MS);
  while (true) {
  }
#else
  while (true) {
    delay(1);
  }
#endif
}

static void prepareForBootloaderEntry() {
  bootloaderEntryPending = true;
  forceSystemOff();

  Serial.println(F("OTA_READY"));
  Serial.flush();
  resetForBootloaderEntry();
}
#endif

static void handleSerialCommandLine(char *line) {
#if ENABLE_SOFTWARE_BOOTLOADER_ENTRY
  if (isBootloaderEntryCommand(line)) {
    prepareForBootloaderEntry();
    return;
  }
#endif

  if (strncmp(line, "KILL", 4) == 0) {
    int value = atoi(line + 4);
    manualKillActive = value != 0;
    if (manualKillActive) {
      // Emergency stop is latched OFF. Releasing it does not restart the rig;
      // a separate SET_ON 1 command is required.
      forceSystemOff();
    }
    return;
  }

  if (strncmp(line, "SET_ON", 6) == 0) {
    int value = atoi(line + 6);
    if (value == 1 && systemCanStart()) {
      // Treat delivery retries as idempotent so an acknowledgement/network
      // failure cannot repeatedly restart autotune.
      if (!heaterEnabled || !motorEnabled) {
        startSystem(millis());
      }
    } else {
      // SET_ON 0 and malformed values both fail safely to OFF. A start request
      // is also rejected while an emergency stop, runtime limit, or sensor
      // fault is active.
      forceSystemOff();
    }
    return;
  }

  if (strncmp(line, "SET_HEATER", 10) == 0) {
    int value = atoi(line + 10);
    if (value == 1 && systemCanStart()) {
      startHeater(millis());
    } else {
      stopHeater();
    }
    return;
  }

  if (strncmp(line, "SET_PUMP", 8) == 0) {
    int value = atoi(line + 8);
    if (value == 1 && systemCanStart()) {
      startPump(millis());
    } else {
      stopPump();
    }
    return;
  }

  if (strncmp(line, "SETPOINT", 8) == 0) {
    float valueC = atof(line + 8);
    int16_t valueCx100 = (int16_t)((valueC * 100.0f) + (valueC >= 0.0f ? 0.5f : -0.5f));
    if (setTargetSetpointCx100(valueCx100)) {
      Serial.print(F("SETPOINT_OK "));
      Serial.println(targetSetpointCx100 / 100.0f, 2);
    } else {
      Serial.println(F("SETPOINT_REJECTED"));
    }
  }
}

static bool serialCommandServiceBlocked() {
#if ENABLE_SOFTWARE_BOOTLOADER_ENTRY
  return bootloaderEntryPending;
#else
  return false;
#endif
}

static void serviceSerialCommands() {
  while (!serialCommandServiceBlocked() && Serial.available() > 0) {
    char c = Serial.read();

    if (c == '\r') {
      continue;
    }

    if (c == '\n') {
      serialCommandBuf[serialCommandIdx] = '\0';
      handleSerialCommandLine(serialCommandBuf);
      serialCommandIdx = 0;
      continue;
    }

    if (serialCommandIdx < (sizeof(serialCommandBuf) - 1)) {
      serialCommandBuf[serialCommandIdx++] = c;
    } else {
      serialCommandIdx = 0;
    }
  }
}

static void updatePumpTelemetry(uint32_t now, uint16_t adc, int16_t tempCx100) {
  if (pumpOnCmd && !pumpWasOn) {
    lastPumpStartMs = now;
    tempBeforeLastPumpCx100 = tempCx100;
    minTempAfterLastPumpCx100 = tempCx100;
    recoveryTimeMs = 0;
    recoveryComplete = false;
    postPumpTracking = false;
    printCsvRow(CSV_PUMP_START, now, adc, tempCx100);
  }

  if (pumpOnCmd && tempCx100 < minTempAfterLastPumpCx100) {
    minTempAfterLastPumpCx100 = tempCx100;
  }

  if (!pumpOnCmd && pumpWasOn) {
    lastPumpEndMs = now;
    postPumpTracking = true;
    if (tempCx100 < minTempAfterLastPumpCx100) {
      minTempAfterLastPumpCx100 = tempCx100;
    }
    printCsvRow(CSV_PUMP_END, now, adc, tempCx100);
  }

  if (postPumpTracking) {
    if (tempCx100 < minTempAfterLastPumpCx100) {
      minTempAfterLastPumpCx100 = tempCx100;
    }
    if (!recoveryComplete && tempBeforeLastPumpCx100 != -32768 &&
        tempCx100 >= tempBeforeLastPumpCx100) {
      recoveryTimeMs = now - lastPumpEndMs;
      recoveryComplete = true;
      postPumpTracking = false;
      printCsvRow(CSV_PUMP_RECOVERED, now, adc, tempCx100);
    }
  }

  pumpWasOn = pumpOnCmd;
}

void setup() {
  pinMode(HEATER_PWM_PIN, OUTPUT);
  pinMode(MOTOR_PIN, OUTPUT);

  heaterSet(0);
  motorSet(false);
  heaterEnabled = false;
  motorEnabled = false; // fail-safe boot: web SET_ON 1 is required

  Serial.begin(115200);

  uint32_t now = millis();
  lastControlMs = now;
  motorCycleStart = now;
  programStartMs = now;
  runtimeExpired = false;
  pumpTempAllowed = false;
  hardKillActive = false;
  sensorFaultActive = false;
  manualKillActive = false;
  serialCommandIdx = 0;
  pumpOnCmd = false;
  pumpCmdPwm = 0;
  pumpWasOn = false;
  postPumpTracking = false;
  recoveryComplete = false;
  lastRateMs = 0;
  lastRateTempCx100 = 0;

  resetAutotune(now);
  forceSystemOff();

  printCsvHeader();
}

void loop() {
  uint32_t now = millis();

  serviceSerialCommands();
#if ENABLE_SOFTWARE_BOOTLOADER_ENTRY
  if (bootloaderEntryPending) {
    delay(1);
    return;
  }
#endif

  if (!runtimeExpired && (now - programStartMs >= MAX_RUNTIME_MS)) {
    runtimeExpired = true;
    forceSystemOff();
  }

  // ----- READ TEMP -----
  uint16_t adc = readAdcAvg();
  bool wasSensorFaultActive = sensorFaultActive;
  sensorFaultActive = adcIndicatesSensorFault(adc, sensorFaultActive);
  int16_t tempCx100 = adcToTempCx100(adc);

  if (lastRateMs == 0) {
    lastRateMs = now;
    lastRateTempCx100 = tempCx100;
    tempRateCPerSec = 0.0f;
  } else if (now != lastRateMs) {
    float dt = (now - lastRateMs) / 1000.0f;
    tempRateCPerSec = ((tempCx100 - lastRateTempCx100) * 0.01f) / dt;
    lastRateMs = now;
    lastRateTempCx100 = tempCx100;
  }

  if (runtimeExpired) {
    pumpOnCmd = false;
    updatePumpTelemetry(now, adc, tempCx100);
    static uint32_t lastRuntimePrint = 0;
    if (now - lastRuntimePrint > 1000) {
      lastRuntimePrint = now;
      printCsvRow(CSV_SAMPLE, now, adc, tempCx100);
    }
    delay(1000);
    return;
  }

  if (sensorFaultActive) {
    forceSystemOff();
    if (!wasSensorFaultActive) {
      printCsvRow(CSV_SENSOR_FAULT, now, adc, tempCx100);
    }
    updatePumpTelemetry(now, adc, tempCx100);
    static uint32_t lastSensorFaultPrint = 0;
    if (now - lastSensorFaultPrint > 1000) {
      lastSensorFaultPrint = now;
      printCsvRow(CSV_SAMPLE, now, adc, tempCx100);
    }
    delay(1000);
    return;
  }

  if (manualKillActive) {
    forceSystemOff();
    updatePumpTelemetry(now, adc, tempCx100);
    static uint32_t lastManualKillPrint = 0;
    if (now - lastManualKillPrint > 1000) {
      lastManualKillPrint = now;
      printCsvRow(CSV_SAMPLE, now, adc, tempCx100);
    }
    delay(1000);
    return;
  }

  if (!heaterEnabled && !motorEnabled) {
    // Remain observably OFF while continuing to service serial commands and
    // publish telemetry. No controller or pump output is evaluated here.
    forceSystemOff();
    updatePumpTelemetry(now, adc, tempCx100);
    static uint32_t lastOffPrint = 0;
    if (now - lastOffPrint > 1000) {
      lastOffPrint = now;
      printCsvRow(CSV_SAMPLE, now, adc, tempCx100);
    }
    delay(1);
    return;
  }

  // ----- CONTROL UPDATE TIMING -----
  if ((now - lastControlMs) >= CONTROL_DT_MS) {
    lastControlMs = now;

    // Note: sensorBad is not meaningful here because adcToTempCx100() clamps.
    bool hardKill  = (tempCx100 >= HEATER_KILL_Cx100);
    bool wasHardKillActive = hardKillActive;
    hardKillActive = hardKill;
    uint8_t pwmCmd = 0;

    if (hardKill) {
      forceSystemOff();
      pwmCmd = 0;
      if (!wasHardKillActive) {
        printCsvRow(CSV_HARD_KILL, now, adc, tempCx100);
      }
    } else if (heaterEnabled) {
      if (controlMode == CTRL_PID_RAMP || controlMode == CTRL_PID_HOLD) {
        pwmCmd = computePidPwm(tempCx100, now);
        if (tempCx100 < HEATER_BIAS_MAX_Cx100) {
          pwmCmd = applyMotorBias(pwmCmd, now);
        }
      } else {
        // During autotune, keep motor ON as required, but do not distort relay data
        // with extra feedforward bias. Warmup/relay remains clean heater command.
        pwmCmd = computeAutotunePwm(tempCx100, now);
      }
      heating = (pwmCmd > 0);
    } else {
      heating = false;
      pwmCmd = 0;
    }

    if (!heating) pwmCmd = 0;
    heaterSet(pwmCmd);
  }

  // ----- MOTOR TIMER -----
  bool pumpWasAllowed = pumpTempAllowed;
  pumpTempAllowed = nextPumpTempAllowed(pumpTempAllowed, tempCx100);

  if (!pumpWasAllowed && pumpTempAllowed) {
    motorCycleStart = now;
  }

  if (motorEnabled && pumpTempAllowed) {
    if ((now - motorCycleStart) >= MOTOR_PERIOD_MS) {
      motorCycleStart = now;
    }
    pumpOnCmd = isMotorOnNow(now);
    if (pumpOnCmd) {
      pumpCmdPwm = computePumpPwm(now);
      motorSetPwm(pumpCmdPwm);
    } else {
      pumpCmdPwm = 0;
      motorSet(false);
    }
  } else {
    pumpOnCmd = false;
    pumpCmdPwm = 0;
    motorSet(false);
  }

  updatePumpTelemetry(now, adc, tempCx100);


  if (lastPwm == 0) {
    digitalWrite(HEATER_PWM_PIN, LOW);
  }

  static uint32_t lastPrint = 0;
  if (now - lastPrint > 1000) {
    lastPrint = now;

    printCsvRow(CSV_SAMPLE, now, adc, tempCx100);
  }
}

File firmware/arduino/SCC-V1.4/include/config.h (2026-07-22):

#ifndef CONFIG_H
#define CONFIG_H

#include <Arduino.h>

// ================== PINS ==================
#define THERM_PIN        A0
#define HEATER_PWM_PIN   6    // MOSFET for heater (PWM)
#define MOTOR_PIN        9    // motor control (PWM-capable on UNO)

// ================== FINAL SETPOINT ==================
#define SETPOINT_Cx100   12500   // 125.00 C final target
#define MOTOR_PWM        155     // 0-255

// ================== CONTROL TIMING ==================
#define CONTROL_DT_MS    700
#define HEATER_PWM_MAX   200

// ================== AUTOTUNE REGION (A) ==================
// Tune in a reachable upper region with motor ON
#define AUTOTUNE_TARGET_Cx100   11500   // 115.00 C relay center
#define AUTOTUNE_WARMUP_Cx100   11000   // enter relay phase near 110.00 C
#define AUTOTUNE_BAND_Cx100       120   // +/-1.20 C around AUTOTUNE_TARGET
#define AUTOTUNE_HEAT_PWM         200
#define AUTOTUNE_CYCLES             5
#define AUTOTUNE_TIMEOUT_MS  1800000UL  // 30 minutes

// ================== PID RAMP TO FINAL ==================
#define PID_RAMP_START_Cx100   AUTOTUNE_TARGET_Cx100
#define PID_RAMP_RATE_Cx100_PER_SEC  15.0f   // 0.15 C/s ramp toward 125 C

// ================== SAFE OPERATING WINDOW ==================
// MgCl2 SCC bath must stay above 120 C and below 130 C.
#define SAFE_TEMP_LOW_Cx100       12000   // 120.00 C
#define SAFE_TEMP_HIGH_Cx100      13000   // 130.00 C

// Lock heater OFF near the upper limit, then only unlock after cooling.
#define OFF_LOCKOUT_HIGH_Cx100    12850   // 128.50 C
#define OFF_LOCKOUT_LOW_Cx100     12650   // 126.50 C

// Only allow new pump doses when the bath has enough thermal headroom.
#define PUMP_ENABLE_Cx100         12500   // allow pump at/above the 125.00 C operating setpoint
#define PUMP_DISABLE_Cx100        12300   // stop pump at/below 123.00 C
#define HEATER_BIAS_MAX_Cx100     12800   // no pump bias at/above 128.00 C

// ================== MOTOR-AWARE COMPENSATION (C) ==================
// Add heater bias shortly before pump ON and while pump is ON
#define MOTOR_PREBIAS_MS        5000UL   // start bias 5 s before motor turns on
#define MOTOR_HEAT_BIAS_PRE       18     // extra PWM before motor pulse
#define MOTOR_HEAT_BIAS_ON        28     // extra PWM during motor ON pulse

// Optional: freeze integrator during pump pulse to reduce windup from known disturbance
#define FREEZE_INTEGRAL_DURING_MOTOR_ON  1

// ================== SAFETY ==================
#define MAX_Cx100          22000
#define MIN_Cx100          -2000
#define HEATER_KILL_Cx100  SAFE_TEMP_HIGH_Cx100   // HARD KILL at 130.00 C

// NTC/ADC rail checks. Open or shorted thermistor wiring normally drives the
// ADC close to 0 or 1023; recovery thresholds add hysteresis for noisy edges.
#define ADC_SENSOR_FAULT_LOW       5
#define ADC_SENSOR_FAULT_HIGH      1018
#define ADC_SENSOR_RECOVER_LOW     10
#define ADC_SENSOR_RECOVER_HIGH    1013

// ================== MOTOR TIMING ==================
#define MOTOR_PERIOD_MS    30000UL   // cycle period
#define MOTOR_ON_MS         1000UL   // ON duration in each cycle
#define MOTOR_START_MS       250UL   // startup kick duration
#define MOTOR_START_PWM      180     // startup kick PWM

// ================== RUNTIME LIMIT ==================
#define MAX_RUNTIME_MS 345600000UL  // 96 hours

// ================== ESP32-DRIVEN UPDATE PREP ==================
// Default off: keeps UART output as CSV telemetry only unless explicitly enabled.
#ifndef ENABLE_SOFTWARE_BOOTLOADER_ENTRY
#define ENABLE_SOFTWARE_BOOTLOADER_ENTRY 0
#endif

// ================== ADC -> TEMP TRANSFER FUNCTION ==================
// Calibrated linear fit:
//   tempC = -0.1871 * adc + 167.97
#define TF_M_C_PER_ADC  (-0.1871f)
#define TF_B_C          (167.97f)

#endif

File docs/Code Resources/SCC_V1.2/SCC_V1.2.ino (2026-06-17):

#include <Arduino.h>
#include <string.h>
#include <stdlib.h>
#include <ctype.h>

// ================== PINS ==================
#define THERM_PIN        A0
#define HEATER_PWM_PIN   6    // MOSFET for heater (PWM)
#define MOTOR_PIN        9    // motor control (PWM-capable on UNO)

// ================== SETPOINT ==================
#define SETPOINT_Cx100   13500   // 135.00 C
#define MOTOR_PWM        155     // 0–255

// ================== PID + AUTOTUNE ==================
#define CONTROL_DT_MS    700
#define HEATER_PWM_MAX   200

// Lock heater OFF above setpoint, then only unlock after cooling below this band
#define OFF_LOCKOUT_HIGH_Cx100 13520  // 135.20C
#define OFF_LOCKOUT_LOW_Cx100   13450  // 134.50C

// Relay autotune around setpoint
#define AUTOTUNE_WARMUP_Cx100   13000    // start relay phase near 130.00C
#define AUTOTUNE_BAND_Cx100      150    // +/-1.50C band
#define AUTOTUNE_HEAT_PWM        200
#define AUTOTUNE_CYCLES            5
#define AUTOTUNE_TIMEOUT_MS  1800000UL  // 30 minutes

// ================== SAFETY ==================
#define MAX_Cx100          22000
#define MIN_Cx100          -2000
#define HEATER_KILL_Cx100  16000   // HARD KILL at 160.00C

// ================== MOTOR TIMING ==================
#define MOTOR_PERIOD_MS   180000UL   // cycle period
#define MOTOR_ON_MS         2000UL   // ON duration in each cycle

// ================== RUNTIME LIMIT ==================
#define MAX_RUNTIME_MS 345600000UL  // 96 hours

// ================== ADC -> TEMP TRANSFER FUNCTION ==================
// Calibrated linear fit:
//   tempC = -0.1871 * adc + 167.97
#define TF_M_C_PER_ADC  (-0.1871f)
#define TF_B_C          (167.97f)

// ================== SERIAL LINE BUFFER ==================
#define CMD_BUF_LEN 64
char cmdBuf[CMD_BUF_LEN];
uint8_t cmdIdx = 0;

// ================== GLOBALS ==================
uint32_t lastControlMs = 0;

uint32_t motorCycleStart = 0;
bool motorEnabled = false;     // SET_ON 1/0 controls this

uint32_t programStartMs = 0;
bool runtimeExpired = false;
bool manualKill = false;       // KILL 1/0 controls this

uint8_t lastPwm = 0;

static bool heating = false;
static bool heaterLockout = false;
static bool pidAutoTuned = false;

enum ControlMode : uint8_t {
  CTRL_AUTOTUNE_WARMUP = 0,
  CTRL_AUTOTUNE_RELAY  = 1,
  CTRL_PID             = 2
};
ControlMode controlMode = CTRL_AUTOTUNE_WARMUP;

// PID terms
float kp = 6.94f;
float ki = 0.10f;
float kd = 120.78f;
float pidIntegral = 0.0f;
float pidLastTempC = 0.0f;
uint32_t pidLastMs = 0;

// Relay autotune bookkeeping
bool relayHigh = true;
int16_t relayPeakHighCx100[AUTOTUNE_CYCLES];
int16_t relayPeakLowCx100[AUTOTUNE_CYCLES];
uint32_t relayPeriodMs[AUTOTUNE_CYCLES];
uint8_t relayCycleCount = 0;
uint8_t relayPeriodCount = 0;
uint32_t lastRiseCrossMs = 0;
int16_t cycleMaxCx100 = -32768;
int16_t cycleMinCx100 = 32767;
uint32_t autotuneStartMs = 0;

// ================== HELPERS ==================
uint16_t readAdcAvg(uint8_t n = 8) {
  uint32_t s = 0;
  for (uint8_t i = 0; i < n; i++) {
    s += analogRead(THERM_PIN);
  }
  return (uint16_t)(s / n);
}

int16_t adcToTempCx100(uint16_t adc) {
  float tempC = (TF_M_C_PER_ADC * (float)adc) + TF_B_C;

  if (tempC > (MAX_Cx100 / 100.0f)) tempC = (MAX_Cx100 / 100.0f);
  if (tempC < (MIN_Cx100 / 100.0f)) tempC = (MIN_Cx100 / 100.0f);

  return (int16_t)(tempC * 100.0f + (tempC >= 0 ? 0.5f : -0.5f));
}

static inline void motorSet(bool on) {
  analogWrite(MOTOR_PIN, on ? MOTOR_PWM : 0);
}

static inline float clampf(float x, float lo, float hi) {
  if (x < lo) return lo;
  if (x > hi) return hi;
  return x;
}

static inline void heaterHardOff() {
  analogWrite(HEATER_PWM_PIN, 0);
  pinMode(HEATER_PWM_PIN, OUTPUT);
  digitalWrite(HEATER_PWM_PIN, LOW);
  lastPwm = 0;
}

static inline void heaterSet(uint8_t pwm) {
  if (pwm == 0) {
    heaterHardOff();
    return;
  }
  if (pwm > HEATER_PWM_MAX) pwm = HEATER_PWM_MAX;
  pinMode(HEATER_PWM_PIN, OUTPUT);
  analogWrite(HEATER_PWM_PIN, pwm);
  lastPwm = pwm;
}

void resetAutotune(uint32_t now) {
  controlMode = CTRL_AUTOTUNE_WARMUP;
  relayHigh = true;
  relayCycleCount = 0;
  relayPeriodCount = 0;
  lastRiseCrossMs = 0;
  cycleMaxCx100 = -32768;
  cycleMinCx100 = 32767;
  autotuneStartMs = now;

  pidIntegral = 0.0f;
  heaterLockout = false;
  pidAutoTuned = false;
  heating = false;
}

void finishAutotune(uint32_t now, int16_t tempCx100) {
  bool usable = (relayCycleCount > 0 && relayPeriodCount > 0);

  if (usable) {
    float highAvgC = 0.0f;
    float lowAvgC  = 0.0f;
    float puSec    = 0.0f;

    for (uint8_t i = 0; i < relayCycleCount; i++) {
      highAvgC += relayPeakHighCx100[i] / 100.0f;
      lowAvgC  += relayPeakLowCx100[i] / 100.0f;
    }
    for (uint8_t i = 0; i < relayPeriodCount; i++) {
      puSec += relayPeriodMs[i] / 1000.0f;
    }

    highAvgC /= relayCycleCount;
    lowAvgC  /= relayCycleCount;
    puSec    /= relayPeriodCount;

    float ampC = (highAvgC - lowAvgC) * 0.5f;
    if (ampC > 0.10f && puSec > 1.0f) {
      float relayAmp = AUTOTUNE_HEAT_PWM * 0.5f;
      float ku = (4.0f * relayAmp) / (PI * ampC);

      kp = clampf(0.60f * ku, 0.10f, 80.0f);
      ki = clampf((2.0f * kp) / puSec, 0.0f, 6.0f);
      kd = clampf((kp * puSec) / 8.0f, 0.0f, 500.0f);

      pidAutoTuned = true;
    } else {
      usable = false;
    }
  }

  if (!usable) {
    kp = 6.94f;
    ki = 0.10f;
    kd = 120.78f;
    pidAutoTuned = false;
  }

  pidIntegral = 0.0f;
  pidLastTempC = tempCx100 / 100.0f;
  pidLastMs = now;
  controlMode = CTRL_PID;

  Serial.print("PID ready. Kp=");
  Serial.print(kp, 4);
  Serial.print(" Ki=");
  Serial.print(ki, 4);
  Serial.print(" Kd=");
  Serial.print(kd, 4);
  Serial.println(pidAutoTuned ? " (autotuned)" : " (fallback)");
}
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

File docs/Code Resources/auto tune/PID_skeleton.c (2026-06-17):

#include <Arduino.h>
#include <math.h>

#ifndef PI
#define PI 3.14159265358979323846
#endif

struct RelayAutotune {
  int16_t setpointCx100 = 10000;
  int16_t bandCx100 = 150;
  uint8_t heatPwm = 200;
  uint8_t maxCycles = 5;
  uint32_t timeoutMs = 30UL * 60UL * 1000UL;

  bool active = false;
  bool relayHigh = true;
  uint8_t cyclesDone = 0;
  uint8_t periodsDone = 0;

  int16_t cycleMaxCx100 = INT16_MIN;
  int16_t cycleMinCx100 = INT16_MAX;

  uint32_t startMs = 0;
  uint32_t lastLowCrossMs = 0;

  float sumHighC = 0.0f;
  float sumLowC = 0.0f;
  float sumPeriodSec = 0.0f;
};

static inline float clampf(float x, float lo, float hi) {
  if (x < lo) return lo;
  if (x > hi) return hi;
  return x;
}

void autotuneStart(RelayAutotune &at, uint32_t nowMs, int16_t currentTempCx100) {
  at.active = true;
  at.startMs = nowMs;
  at.cyclesDone = 0;
  at.periodsDone = 0;
  at.sumHighC = 0.0f;
  at.sumLowC = 0.0f;
  at.sumPeriodSec = 0.0f;
  at.lastLowCrossMs = 0;

  at.relayHigh = (currentTempCx100 < at.setpointCx100);
  at.cycleMaxCx100 = currentTempCx100;
  at.cycleMinCx100 = currentTempCx100;
}

uint8_t autotuneUpdate(
  RelayAutotune &at,
  int16_t tempCx100,
  uint32_t nowMs,
  bool &done,
  bool &ok,
  float &Ku,
  float &Pu
) {
  done = false;
  ok = false;
  Ku = 0.0f;
  Pu = 0.0f;

  if (!at.active) return 0;

  if ((nowMs - at.startMs) > at.timeoutMs) {
    at.active = false;
    done = true;
    ok = false;
    return 0;
  }

  const int16_t hiThresh = at.setpointCx100 + at.bandCx100;
  const int16_t loThresh = at.setpointCx100 - at.bandCx100;

  if (at.relayHigh) {
    if (tempCx100 > at.cycleMaxCx100) at.cycleMaxCx100 = tempCx100;

    if (tempCx100 >= hiThresh) {
      at.relayHigh = false;
      at.cycleMinCx100 = tempCx100;
      return 0;
    }
    return at.heatPwm;
  } else {
    if (tempCx100 < at.cycleMinCx100) at.cycleMinCx100 = tempCx100;

    if (tempCx100 <= loThresh) {
      at.sumHighC += (at.cycleMaxCx100 / 100.0f);
      at.sumLowC  += (at.cycleMinCx100 / 100.0f);
      at.cyclesDone++;

      if (at.lastLowCrossMs != 0) {
        at.sumPeriodSec += (nowMs - at.lastLowCrossMs) / 1000.0f;
        at.periodsDone++;
      }

      at.lastLowCrossMs = nowMs;

      if (at.cyclesDone >= at.maxCycles && at.periodsDone > 0) {
        float highAvgC = at.sumHighC / at.cyclesDone;
        float lowAvgC  = at.sumLowC  / at.cyclesDone;
        float PuSec    = at.sumPeriodSec / at.periodsDone;

        float a = 0.5f * (highAvgC - lowAvgC);
        float d = 0.5f * at.heatPwm;

        bool usable = (a > 0.10f && PuSec > 1.0f);

        if (usable) {
          Ku = (4.0f * d) / (PI * a);
          Pu = PuSec;
          ok = true;
        } else {
          ok = false;
        }

        at.active = false;
        done = true;
        return 0;
      }

      at.relayHigh = true;
      at.cycleMaxCx100 = tempCx100;
      return at.heatPwm;
    }

    return 0;
  }
}

void znPidFromKuPu(float Ku, float Pu, float &Kp, float &Ki, float &Kd) {
  Kp = 0.60f * Ku;
  Ki = (Pu > 0.0f) ? (2.0f * Kp / Pu) : 0.0f;
  Kd = (Kp * Pu) / 8.0f;

  Kp = clampf(Kp, 0.05f, 200.0f);
  Ki = clampf(Ki, 0.0f, 50.0f);
  Kd = clampf(Kd, 0.0f, 1000.0f);
}

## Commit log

2026-06-04 Initial SCC control platform V0.1
    [partitions_ota.csv]
2026-06-04 V0.1.1 - Initial OTA features for both arduino and ESP32
2026-06-08 SCC control V0.1.1.4 - modified ESP32 Relay firmware to use MQTT instead of IoT Hub - Updated WiFi credentials header to include MQTT broker configuration. - Removed IoT Hub related definitions and f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
2026-06-12 SCC control V0.1.1.5 - Added Heater Testing, Telemetry Testing (Relay and Parsing), NTC Testing, Motor Testing
    [arduino_telemetry_sample.csv]
2026-06-16 Enhance telemetry handling and Wi-Fi configuration in ESP32 firmware
2026-06-17 SCC control V0.1.1.6: feat: Add setpoint command handling in firmware and update tests
    - Implemented a new "SETPOINT" command in the firmware to allow dynamic setpoint adjustments.
    - Updated the main control logic to handle the new command and provide appropriate feedback.
    - Enhanced unit tests to cover scenarios for setting and rejecting out-of-band setpoints.
    - Modified existing tests to align with the new target setpoint variable.
    - Updated the HMI dashboard to reflect changes in firmware interactions, including updated messaging for Arduino and ESP32.
    - Removed obsolete ESP32 testing files and configurations as the focus shifts to Arduino.
    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
2026-06-17 SCC control V0.1.1.6: Remove obsolete files and code from ESP32-Relay firmware
    - Deleted autogenerated CMakeLists.txt as it is no longer needed.
    - Removed main.c file containing the core application logic, as it has been replaced or is no longer in use.
    - Cleared test directory and associated test files, including README and test_relay_core.c, to streamline the project structure.
    - Deleted README.md file that provided outdated information about the ESP32 firmware project.
    [partitions_ota.csv]
2026-06-17 SCC control V0.1.1.6: Add new documentation files for SCC setup and TDM
    - Added "SCC setup photo.JPG" to provide a visual reference for SCC setup.
    - Included "SCC 316 TDM.docx" as a new document for TDM-related information.
    - Added temporary file "~$C 316 TDM.docx" which appears to be a lock file for the document.
    [316 Updated Drawing v1.dwg, Container-3d print.stl, Corrosion Cell CAD.step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]
2026-06-21 SCC control V0.1.1.6: Update target temperature and heater thresholds in Arduino heater testing firmware
2026-07-08 Refactor telemetry handling to allow nullable fields and improve error handling in telemetry parsing and storage
    [pump_cycles.py, telemetry_parser.py]
2026-07-22 SCC control V0.1.1.7
    [316 Updated Drawing v1.dwg, Container-3d print.stl, Corrosion Cell CAD.step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]
2026-10-08 SCC control V1.0 Patches: Enhance control commands and UI feedback for power management
    - Updated firmware API to handle command acknowledgments and ensure pending commands are retried on failure.
    - Improved Operations Dashboard to provide clearer feedback on power states and emergency controls.
    - Added telemetry mode reporting for system status.
    - Refined CSS styles for safety buttons and states.
    - Expanded test coverage for power control and command acknowledgment scenarios.
    [controller.cpp, main.cpp, nuc_gateway.py]
2026-10-08 SCC control V1.1 Patches: Enhance control commands and UI feedback for power management
    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
    [controller.cpp, main.cpp, nuc_gateway.py]
2026-10-09 Increase motor ON duration from 1000ms to 3000ms for improved performance
2026-10-09 Revert "Increase motor ON duration from 1000ms to 3000ms for improved performance"
    This reverts commit 6f33353b2f2d0b0fea83931f832cdf89439492a2.
    [config.h]
2026-10-09 Add telemetry training dataset
    [esp32_telemetry.csv]

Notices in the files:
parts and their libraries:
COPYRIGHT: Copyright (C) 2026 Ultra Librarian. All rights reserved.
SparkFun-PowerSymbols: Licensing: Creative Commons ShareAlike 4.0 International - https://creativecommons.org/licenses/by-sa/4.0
